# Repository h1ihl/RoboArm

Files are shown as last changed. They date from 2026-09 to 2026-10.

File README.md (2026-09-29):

# Desk Arm — Low-Cost 3-DOF Desktop Robot Arm

A small tabletop 3-DOF robot arm (base yaw, shoulder, elbow, plus a two-finger
gripper), 3D-printed and built on hobby servos, aimed at CAD $50–70 and hard
capped at $100. V1 is a manually/programmatically controlled physical arm.
V2 (not started) adds a camera, object detection and an AI agent on top of the
same control API.

**Status: Phase 0 (Requirements) complete — design review signed off, CAD not
yet started.** See [`docs/requirements.md`](docs/requirements.md) for the
decision gate and [`docs/planning_guide.pdf`](docs/planning_guide.pdf) for the
full write-up.

## Chosen configuration — Configuration B

| | |
|---|---|
| Reach | 315 mm |
| Payload | 55 g |
| Base / Shoulder / Elbow | MG90S / MG996R / MG996R |
| Wrist (slaved, keeps jaws level) | SG90 |
| Gripper | MG90S, two-finger compliant jaws |
| Controller | ESP32 DevKit, USB serial |
| Power | 6 V 3 A regulated, separate from MCU 5 V rail |
| Shoulder safety factor | 2.44 |
| Purchase cost | ≈ CAD $59 (typical lab sourcing) |

Fallback Configurations A (ultra-budget, $48–55), C (university-sourced,
$17–35) and D (stronger, $85–95) share the same CAD, firmware and software —
see §14 of the planning guide.

## Repository layout

```
README.md                    you are here
docs/                         requirements, calculations, BOM, procedures, wiring diagram, the LaTeX planning guide + PDF
firmware/arm_firmware/        ESP32 sketch — servo control, joint limits, slew limiting, serial protocol
software/                     Python control layer — kinematics, trajectory, transport, CLI
cad/                           SolidWorks project layout, parametric strategy, part/config naming (files added as they're modelled)
calculations/                  the torque/mass/stability numbers as a runnable, checkable script
artifacts/                     saved copies of design artifacts (e.g. the interactive design-review page)
tools/latex/                   self-contained LaTeX engine used to build docs/planning_guide.pdf
```

## Documentation map

| Doc | Covers |
|---|---|
| [`docs/requirements.md`](docs/requirements.md) | DOFs, dimensions, payload, workspace, budget, the decision gate |
| [`docs/actuator_selection.md`](docs/actuator_selection.md) | Torque calculations, servo table, SG90 vs MG90S gripper decision |
| [`docs/mechanical_design.md`](docs/mechanical_design.md) | Geometry, mass budget, material assignment, print orientation rules, SolidWorks parametric strategy |
| [`docs/electronics.md`](docs/electronics.md) | Controller choice, wiring, serial protocol |
| [`docs/wiring_diagram.svg`](docs/wiring_diagram.svg) | Full wiring diagram — pin-out, power rail, grounding |
| [`docs/power_system.md`](docs/power_system.md) | Current budget, supply spec, brownout protection |
| [`docs/kinematics.md`](docs/kinematics.md) | Forward/inverse kinematics derivation, validation order |
| [`docs/bill_of_materials.md`](docs/bill_of_materials.md) | BOM A (purchase) and BOM B (university-sourced) |
| [`docs/assembly.md`](docs/assembly.md) | Build order, torque/adhesive notes, calibration procedure |
| [`docs/testing.md`](docs/testing.md) | Per-phase test plan, acceptance criteria |
| [`docs/v2_ai_roadmap.md`](docs/v2_ai_roadmap.md) | What V2 adds and why V1's API doesn't need to change |
| [`docs/planning_guide.pdf`](docs/planning_guide.pdf) | All of the above, consolidated into one LaTeX-typeset document |

## Software quick start

```bash
cd software
python -m robot.kinematics        # runs the FK/IK self-test, no hardware needed
python cli.py --port COM5         # interactive control, once the arm is wired up
```

`software/robot/arm.py` exposes the six calls everything else — including the
future V2 agent — is meant to use: `home()`, `move_joints()`, `move_to()`,
`grip()`, `pickup()`, `place()`.

## Firmware quick start

Install the `esp32` board package (Boards Manager) and the `ESP32Servo`
library (Library Manager) in the Arduino IDE, open
`firmware/arm_firmware/arm_firmware.ino`, select your ESP32 board (e.g.
"ESP32 Dev Module"), upload, then talk to it at 115200 baud — `PING` should
answer `OK ARM v1`. Full command reference in `docs/electronics.md`.

## Build a fresh PDF

```powershell
.\tools\latex\tectonic.exe docs\planning_guide.tex --outdir docs
```

See `tools/latex/README.md` for details.

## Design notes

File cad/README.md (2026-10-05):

# CAD

No SolidWorks files exist yet — Phase 2 (Mechanical design) starts here.
SolidWorks files are proprietary binary formats this tool can't author, so
this folder currently documents the structure and naming convention to
build against, per `docs/mechanical_design.md`'s parametric strategy. Add
real `.SLDPRT` / `.SLDASM` files as they're modelled; keep this README's
part list in sync as the source of truth for what should exist.

## Layout

```
cad/
├── equations.txt     global variables, exported from SolidWorks — import into every new part
├── parts/            individual part files (.SLDPRT)
├── assemblies/        sub- and top-level assemblies (.SLDASM)
└── exports/           STEP/STL exports for printing and sharing
```

## Global parameters (one equations/variables file, referenced everywhere)

`equations.txt` is the exported copy of this table. Import it
(Tools > Equations > Import) into each new part; when a value changes,
change it once, re-export, and re-import into existing parts.

| Parameter | Symbol | Default (Config B) |
|---|---|---:|
| Shoulder height | `h0` | 75 mm |
| Upper arm length | `L1` | 120 mm |
| Forearm length | `L2` | 120 mm |
| Wrist→TCP length | `L3` | 75 mm |
| Link plate thickness | `t_link` | 3 mm |
| Link plate depth (bending direction) | `w_link` | 20 mm — matches the deflection calc in `calculations/engineering_calcs.py` |
| Twin-plate gap | `w_gap` | 20 mm — provisional, set by the elbow servo mount design |
| Bracket thickness | `t_bracket` | 4 mm |
| Pin diameter | `d_pin` | 4 mm (M4) |
| Gripper pivot pin diameter | `d_pin_gripper` | 3 mm (M3) |
| Nominal clearance | `c_fit` | 0.2 mm — **measured**, PLA (see below) |
| Gripper pivot clearance | `c_fit_pivot` | `c_fit` + 0.05 mm = 0.25 mm — chosen, not coupon-verified for free spin |

`c_fit` was confirmed with the tolerance coupon on 2026-10-01: Prusa
Core One, Prusament PLA, 0.4 mm nozzle, 0.2 mm layers — +0.20 mm gave the
best snug fit on both the M4 and M3 hole rows. PETG is still untested;
re-run the coupon in PETG before printing PETG parts (brackets, jaws, horn
adapters) and add a separate `c_fit_petg` if it lands somewhere else.
`c_fit_pivot` is the free-rotation clearance for the gripper jaw pins,
set to 0.25 mm (`c_fit` + 0.05 mm) — a chosen value between the snug 0.2 mm
fit and the original 0.3 mm estimate. Check a pin for free spin in the
printed 3.25 mm coupon hole before relying on it.

## Servo-pocket library feature (two-row design table)

| Row | Body (mm) | Mounting-ear span | Servos |
|---|---|---:|---|
| `standard` | 40.7 × 19.7 × 42.9 | 49.5 mm | MG996R, MG995, DS3218 |
| `micro` | 22.8 × 12.2 × 22.5 | 32 mm | MG90S, SG90, MG92B |

Every servo mount part references this feature and picks a row — swapping
an MG996R for an MG90S (or vice versa, per the fallback configurations in
`docs/requirements.md`) is then a design-table row change, not a redesign.

## Part list (target — Configuration B)

| Part | Qty | File (suggested) | Notes |
|---|---:|---|---|
| Base plate | 1 | `parts/base_plate.SLDPRT` | Includes ballast cavity + snap-lid feature, camera-mast mounting bosses for V2 |
| Ballast cavity lid | 1 | `parts/ballast_lid.SLDPRT` | Snap-fit |
| Ballast block | 1 | `parts/ballast_block.SLDPRT` | Milled mild steel, not printed — size the cavity pocket to this part once it's cut (`docs/mechanical_design.md` §Ballast); bolt or press-fit, don't leave it loose |
| Column | 1 | `parts/column.SLDPRT` | Carries the two 608ZZ bearings |
| Turret | 1 | `parts/turret.SLDPRT` | Bolts to base-servo horn |
| Shoulder bracket | 1 | `parts/shoulder_bracket.SLDPRT` | Print flat — see mechanical_design.md rule 1. FEA candidate. |
| Elbow bracket | 1 | `parts/elbow_bracket.SLDPRT` | Print flat, same rule. |
| Upper-arm side plate | 2 | `parts/upper_arm_plate.SLDPRT` | Twin-plate box section; symmetric, so one part printed twice. Spec below. |
| Forearm side plate | 2 | `parts/forearm_plate.SLDPRT` | Save As from the upper-arm plate, `L1` → `L2`; keep as a separate file so Config-A-Short (`L2 = 80 mm`) works |
| Link spacers | qty per BOM | `parts/link_spacer.SLDPRT` | Parametric tube, length = `w_gap`; bolt size is a free choice (M3 keeps it clear of the M4 pivots) |
| Servo-horn adapter | 3 | `parts/horn_adapter.SLDPRT` | Bolts to the servo's metal horn — never a printed spline |
| Wrist mounting face | 1 | `parts/wrist_face.SLDPRT` | Common 24×24 mm interface — fixed bracket / SG90 slave / future linkage all mount here |
| Fixed wrist bracket | 1 (alt.) | `parts/wrist_fixed.SLDPRT` | Configuration-A fallback |
| Gripper jaw | 2 | `parts/gripper_jaw.SLDPRT` | Mirror pair, meshed gear sectors, compliant tip |
| Gripper drive link | 1 | `parts/gripper_link.SLDPRT` | |
| Cable clip | qty as needed | `parts/cable_clip.SLDPRT` | Unloaded, PLA, print in whatever's on the machine |

### Link side plate spec (upper arm; forearm identical with `L2`)

- Profile: `w_link` (20 mm) deep slot, both ends rounded at radius
  `w_link / 2`, concentric with the pivot holes. Overall ≈ 140 × 20 mm
  at `L1 = 120 mm`.
- Thickness `t_link` (3 mm), printed flat, hole axes normal to the bed.
- Two pivot holes, diameter `d_pin + c_fit` (4.2 mm), centre-to-centre
  `L1` — all driven from variables, nothing typed in.
- A few spacer-bolt holes along the plate; the gap between the twin
  plates is `w_gap`, which the servo mount design drives.
- Symmetric profile so one file prints twice with no mirrored copy.
- Check: print one plate, pass an M4 bolt through both pivot holes and
  caliper the centre distance — 120 ± 0.2 mm.

## Configurations to define in the top-level assembly

| Configuration | `L2` | Notes |
|---|---:|---|
| `Config-A-Short` | 80 mm | Fallback geometry — see `docs/requirements.md` trigger conditions |
| `Config-B-Standard` | 120 mm | Default — matches the numbers throughout `docs/` |

## Before printing anything

Done for PLA (see Global parameters above). For PETG parts, print the
tolerance coupon described in `docs/mechanical_design.md` in PETG and
confirm `c_fit = 0.2 mm` is actually right for that material before
committing it globally.

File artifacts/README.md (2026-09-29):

# Artifacts

`design_review.html` is a saved copy of the interactive design-review page
published earlier in this project
(https://claude.ai/code/artifact/120ad4c1-6e6d-4bc8-b303-615aa0728409) --
open it directly in a browser, no server needed. It was the first pass
through the numbers, before they were re-derived as runnable code.

**Two figures in it are superseded.** `calculations/engineering_calcs.py`
(run against real Python, not hand-arithmetic) caught two rounding slips
that made it into this page but not into `docs/`:

| Figure | This page says | Corrected (docs/, planning_guide.pdf) |
|---|---|---|
| Base tipping safety factor, ballasted | 2.26 | **2.22** |
| Wrist-servo required torque / SF | 0.51 kg·cm / SF 3.5 | **0.58 kg·cm / SF 3.08** |

Neither changes any design decision (both still clear their safety-factor
floors comfortably) -- treat `docs/` and `docs/planning_guide.pdf` as
authoritative; keep this page as the design-review record, not as the
current numbers.

**Controller updated in place.** The page originally recommended an Arduino
Nano; it's been edited to match the later ESP32 swap (`docs/electronics.md`)
-- cost, pin/library notes, the 3.3 V servo-jitter risk, and every table
that named the controller. This one change was applied directly rather than
left as a footnoted discrepancy like the two figures above, since it's a
component substitution the rest of the page's numbers don't depend on.

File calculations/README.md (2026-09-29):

# Calculations

`engineering_calcs.py` is a runnable, self-checking reproduction of every
number in `docs/actuator_selection.md`, `docs/mechanical_design.md` and
`docs/planning_guide.pdf` — mass budget, joint torque, servo safety factors,
gripper force, base tipping stability, and printed-link deflection.

```
python calculations/engineering_calcs.py
```

Runs a self-test against the published figures first (raises `AssertionError`
if something no longer matches), then prints a full report. Change a
geometry or mass constant at the top of the file and re-run to see how every
downstream number moves — this is the tool to reach for before committing to
a fallback configuration (`docs/requirements.md`).

**Verified 2026-09-18** against Python 3.12 — all figures match the
published docs within rounding tolerance. This run is also what caught two
rounding slips in the original hand-worked design review before they made
it into the docs: the ballasted tipping safety factor is **2.22**, not 2.26,
and the wrist-servo torque is **0.58 kg·cm** (SF 3.08), not 0.51 (SF 3.5) —
both now corrected everywhere in `docs/`.

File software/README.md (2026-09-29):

# Software

Python control layer -- kinematics, trajectory shaping, the serial
transport, and the public `Arm` API everything (CLI, demo sequences, and
eventually the V2 agent) is meant to call through. Architecture and the
V1/V2 boundary are in `docs/electronics.md` and `docs/v2_ai_roadmap.md`.

## Install

```bash
pip install -r requirements.txt
```

Only needed for real hardware (`pyserial`). Kinematics and the demo
sequences run against a simulated arm with no dependencies at all.

## Layout

```
robot/
├── config.py        geometry, joint limits, workspace bounds, servo calibration -- the one file to tune
├── kinematics.py     fk(), ik(), reachable(), path_safe() -- see docs/kinematics.md
├── trajectory.py      eased joint-space interpolation for Cartesian moves
├── transport.py        serial line protocol + a SimulatedTransport for hardware-free testing
└── arm.py              class Arm -- the public API (home, move_joints, move_to, grip, pickup, place)
cli.py                  interactive shell: python cli.py --port COM5
sequences.py             demo/test routines used in docs/testing.md
```

## Try it with no hardware attached

```bash
python -m robot.kinematics     # FK/IK self-test
python sequences.py wave       # runs against a simulated arm, prints every command
python cli.py                  # interactive shell, simulated
```

Once the arm is wired up (`docs/assembly.md`), add `--port COM5` (or
whatever the ESP32 enumerates as) to `cli.py` / `sequences.py`, or pass
`port="COM5"` to `Arm()` directly.

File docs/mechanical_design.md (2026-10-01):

# Mechanical design

## Geometry

Equal-length links: `L₁ = L₂ = 120 mm`. Deliberate, not arbitrary — equal
lengths (a) make the printed parts nearly identical, so it's one parametric
sketch with two configurations rather than two separate designs, (b)
maximise the folded-to-extended reach ratio, and (c) put the workspace's
inner boundary where the turret already is instead of leaving dead space.
`h₀ = 75 mm` (shoulder height) is the minimum that lets the elbow fold
without hitting the turret; `L₃ = 75 mm` (wrist→TCP) covers jaw depth plus
clearance to grip a 30 mm object. Every dimension traces back to the torque
budget in `docs/actuator_selection.md` — none were picked for looks.

| Parameter | Value |
|---|---|
| Shoulder height h₀ | 75 mm |
| Upper arm L₁ | 120 mm |
| Forearm L₂ | 120 mm |
| Wrist→TCP L₃ | 75 mm |
| Max TCP reach | 315 mm |
| Base footprint | 180 × 180 mm |
| Jaw opening | 0–55 mm |

## Structure: twin side plates

Links are two printed side plates on printed spacers — a box section that's
stiff in bending, prints flat with no supports, and puts every bolt in
double shear. Roughly 14 unique parts / 20 printed pieces / ~300 g of
filament / 18–22 h print time total for the arm.

## Material assignment

| Part | Material | Why |
|---|---|---|
| Base plate, column, turret | PLA | Stiffness and flatness; nothing here is impact-loaded |
| Upper arm, forearm links | PLA | E ≈ 3.5 GPa vs. PETG's 2.0 — 75% stiffer per section; deflection is what matters in a link |
| Shoulder and elbow brackets | PETG | Highest bending stress in the machine, and bending is where poor layer adhesion shows up first |
| Servo horn adapters | PETG | Small, bolted, loaded in a direction that wants to peel layers apart |
| Gripper jaws | PETG | Designed to flex (see compliant tip, actuator_selection.md); PLA would snap at the flex section |
| Spacers, clips, tray | PLA | Unloaded — print in whatever's on the machine |
| Ballast block | Mild steel, milled | Not printed — see Ballast below |

## Ballast

A solid milled block, not loose fill (sand, washers, etc.) — a fixed,
known mass at a fixed position matches the stability calc's assumption
exactly, and doesn't shift the CoM as the base rotates the way loose fill
can.

**Mild steel, ~50–55 cm³ for the 400 g target** (density ≈ 7.85 g/cm³):
a 60 × 60 × 15 mm block is ≈424 g, comfortably clearing the minimum with
margin to spare for the mass the stability calc doesn't otherwise account
for (hardware, wiring, ballast-cavity lid). Steel over aluminium here
specifically for the footprint: at the same mass, aluminium
(≈2.70 g/cm³) needs ~3× the volume, and the ballast cavity is already
competing for space with the column and base-servo mount inside the
180 × 180 mm base. Weigh the actual cut block before final install and
trim (or pick a slightly larger blank) to clear 400 g — mild steel density
varies enough between alloys (7.75–7.87 g/cm³) that this is a
measure-don't-assume step, consistent with the rest of this project's
philosophy on anything safety-factor-adjacent.

**Bolt or press-fit it into the cavity** — don't let it sit loose. A block
free to slide during the base's rotation defeats the fixed-CoM assumption
above, and turns a designed-in stability margin into an unmeasured one.

Design the ballast cavity pocket to the block's actual milled dimensions
once cut, not the other way around — CAD (Phase 2) hasn't started yet, so
there's no existing pocket geometry to retrofit.

Print settings throughout: 0.4 mm nozzle, 0.2 mm layers, **4 perimeters**,
30% gyroid infill, 5 top/bottom layers. Perimeter count dominates strength in
a thin printed part — 4 walls at 20% infill beats 2 walls at 60%, and weighs
less.

## Layer orientation — the three rules that decide whether this works

1. **Print brackets flat, never standing up.** A shoulder bracket printed
   upright has its layer planes perpendicular to the bending stress, so the
   load tries to peel layers apart — roughly 40–60% of in-plane strength.
   Printed flat, the same stress runs along continuous extrusions instead.
2. **Every bolt hole axis is normal to the build plate.** Bolts then clamp
   *across* layers in compression, which printed plastic handles well,
   instead of trying to split them apart.
3. **Never print a servo spline.** A printed 25-tooth spline will round off —
   not might, will. Bolt the metal horn that came with the servo to the
   printed part with 2–3 M2 screws and let the horn take the torque. This is
   the single most common failure mode in printed arms, and it's designed
   out from part one rather than discovered after a reprint.

## Where SolidWorks Simulation earns its time — and where it doesn't

**Worth running (2 studies):**
- **Shoulder bracket** — 0.44 N·m through a bolted interface with a stress
  concentration at the servo cutout. The one part where intuition is
  unreliable.
- **Upper-arm link** — check the elbow-servo pocket; expect the answer to be
  "add a 3 mm fillet."

**Not worth running:** everything else. The hand calculation below already
answers the question, and running FEA on a part that's obviously fine just
burns an afternoon.

```
Upper-arm tip deflection, 1.3 N at 120 mm, twin 20 × 3 mm plates:
  I = 2 × (3 × 20³)/12 = 4000 mm⁴
  δ = FL³/(3EI) = 1.3 × 120³ / (3 × 2500 × 4000) = 0.075 mm
```

**Seventy-five microns.** The structure is ~80× stiffer than the servo
backlash it's bolted to (see `docs/kinematics.md` — repeatability is
backlash-limited to ±5–8 mm). **Do not thicken these links.** Every gram
added buys nothing measurable and costs shoulder safety factor directly —
this is the one place in the project where "more robust" would make the
robot objectively worse.

If FEA is run on either study, use orthotropic material properties (printed
plastic is not isotropic) and treat the result as a comparison between two
design variants, not an absolute number.

## Parametric strategy for SolidWorks

- **One global variable/equations file** driving `L1`, `L2`, `L3`, `h0`,
  plate thickness and pin diameter across every part.
- **A servo-pocket library feature with a two-row design table** — standard
  (MG996R: 40.7 × 19.7 × 42.9 mm body, 49.5 mm mounting-ear span) and micro
  (MG90S/SG90: 22.8 × 12.2 × 22.5 mm, 32 mm span). Every servo mount
  references it, so swapping an MG996R for an MG90S is a configuration
  change, not a redesign. This is what makes Configurations A–D one robot
  instead of four (brief §28).
- **Assembly mated to reference planes and axes**, never face-to-face
  between links, so changing `L1` rebuilds the assembly instead of
  erroring it out.
- **Configurations**: `Config-A-Short` (`L2 = 80 mm`) and
  `Config-B-Standard` (`L2 = 120 mm`) from the same part files.
- **0.2 mm nominal clearance** on every pin and pocket. Print a tolerance
  coupon first (a small test part with a few pin/hole pairs at different
  clearances) and adjust once, globally, via the variables file — cheaper
  than reprinting full parts to find the right fit.
  **Measured 2026-10-01** (Prusa Core One, Prusament PLA, 0.4 mm nozzle,
  0.2 mm layers, 3 mm plate, holes axis-normal to the bed): +0.20 mm gave
  the best snug fit on both the M4 (`d_pin`) and M3 (`d_pin_gripper`) hole
  rows, so `c_fit = 0.2 mm` stands as a measured value, not an assumption.
  The calculated estimate beforehand was ~0.15 mm for PLA structural fits —
  close, but the measurement wins. Still open: PETG (untested, needs its own
  coupon) and the free-rotation `c_fit_pivot`, set to 0.25 mm
  (`c_fit` + 0.05 mm) by choice for the gripper jaw pins — it still wants a
  spin-freely check in the printed 3.25 mm coupon hole rather than the
  snug-fit one used for `c_fit`.

## Suggested file layout (see `cad/README.md`)

```
cad/
├── parts/            individual SolidWorks part files (.SLDPRT)
├── assemblies/        sub- and top-level assemblies (.SLDASM)
└── exports/           STEP/STL exports for printing and sharing
```

No SolidWorks files exist yet — Phase 2 (Mechanical design) starts here.
`cad/README.md` has the part list, naming convention and design-table spec
to build against.

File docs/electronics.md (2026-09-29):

# Electronics

## Architecture

```
   PC ──USB──▶ ESP32 ──────5 × PWM signal──▶ servos
                    │                              ▲
                    └──── GND ═══════ common ══════╪═══ GND
                                                   │
    6 V 3 A supply ──fuse──┬── 2 × 1000 µF ────────┘
                           └── V+ rail to all five servos
```

Full pin-out and wiring shown in [`docs/wiring_diagram.svg`](wiring_diagram.svg)
— open it in a browser, no build step needed.

## Controller: ESP32 (DevKitC or equivalent)

**Revised from the original Arduino Nano choice** — see the reasoning below;
nothing else about the architecture changed. The ESP32 is 3.3 V logic where
the Nano was native 5 V, which is the one real trade-off:

- Hobby servos decode PWM through an analog RC input stage, and in
  practice a 3.3 V "high" clears that threshold on the SG90/MG90S/MG996R
  family used here — this is a well-worn combination, not a gamble. The
  documented failure mode is occasional jitter on a specific unit, not a
  hard incompatibility. **Test each servo before final assembly**; if one
  jitters, add a 74HCT125/74AHCT125 quad buffer (~$1, one chip covers all
  five signal lines) between the GPIO and that signal wire to get a clean
  5 V pulse. Not included in the base BOM because most builds won't need
  it — this is the documented fallback, not a default component.
- Requires the **ESP32Servo** library instead of the stock `Servo.h` (the
  ESP32 Arduino core doesn't ship one); API is functionally the same
  `attach()` / `writeMicroseconds()` pair, just backed by the chip's LEDC
  PWM peripheral instead of a hardware timer. See
  `firmware/arm_firmware/arm_firmware.ino` for the setup boilerplate this
  adds (timer allocation, per-channel pulse range).
- In exchange: a dual-core chip with far more flash/RAM/GPIO than this
  project needs, a similar street price to the Nano, and — unused in V1,
  but noted for `docs/v2_ai_roadmap.md` — Wi-Fi/BT already on the board if
  V2 ever wants the arm untethered from the PC.

| Board | Cost | Logic | Assessment |
|---|---:|---|---|
| **ESP32 DevKit (chosen)** | $12 | 3.3 V | `ESP32Servo` library, USB-serial via onboard CP2102/CH340 — install its driver before you need it. Test 3.3 V servo latching per-unit; level-shifter fallback above. |
| Arduino Nano | $9 | 5 V | Native servo levels, no latching question, stock `Servo.h`. The straightforward fallback if an ESP32 isn't available or a servo won't latch cleanly at 3.3 V even with a level shifter — same firmware minus the ESP32Servo-specific setup calls, same pin roles, same protocol. |
| Arduino Uno | — | 5 V | Electrically identical to the Nano, bulkier. Take this if the lab has one. |
| Raspberry Pi Pico | $7 | 3.3 V | Better PWM hardware, cheaper, MicroPython instead of Arduino C++. Same 3.3 V latching consideration as the ESP32. |

**Deliberately not included:**
- **PCA9685 driver board** — five servos fit on five ESP32 GPIOs with the
  `ESP32Servo` library. The board solves a problem (running out of timers)
  that starts around twelve servos. $6 and a whole I²C bus for nothing here.
- **Encoders / current sensing** — hobby servos have no position-feedback
  path to the MCU; external encoders would mean closing a loop the servo
  already closes internally. Real value, wrong project.
- **Limit switches** — servos are absolute-position devices; they know where
  they are at power-on. Homing switches solve a stepper problem this arm
  doesn't have.

Assembly is a small piece of perfboard on the base plate: five 3-pin servo
headers, a barrel jack, the bulk capacitors, a fuse, and jumper wires to the
ESP32's GPIO/GND header pins — under an hour of soldering.

### GPIO pin selection

`firmware/arm_firmware/arm_firmware.ino` uses GPIO13 (base), GPIO14
(shoulder), GPIO27 (elbow), GPIO26 (wrist), GPIO25 (gripper) — five
general-purpose, LEDC-PWM-capable pins, chosen to avoid:

- **GPIO 0, 2, 5, 12, 15** — boot-strapping pins. A servo signal wire
  yanking one of these during power-on can change the chip's boot mode.
- **GPIO 34–39** — input-only, can't drive a servo signal at all.
- **GPIO 1, 3** — UART0, i.e. the USB-serial link back to the PC.

Any other general-purpose GPIO works as a substitute if a specific board's
layout makes a different pin more convenient — there's nothing special
about this exact set beyond satisfying the three exclusions above.

## Serial protocol

ASCII, line-oriented, one command per line, every command answered.
Debuggable from a plain serial monitor with no tooling — which matters a
great deal on the first evening the arm doesn't move.

| Command | Reply | Purpose |
|---|---|---|
| `PING` | `OK ARM v1` | Port identification and liveness |
| `J <base> <sh> <el>` | `OK` \| `ERR LIMIT <joint>` | Absolute joint angles, degrees. Wrist follows automatically. |
| `G <0-100>` | `OK` | Gripper, 0 = closed, 100 = open |
| `US <ch> <µs>` | `OK` \| `ERR RANGE` | Raw pulse width — calibration only, still bounded by limits.h. `ch` is `B`/`S`/`E`/`W`/`G` (base/shoulder/elbow/wrist/gripper) |
| `HOME` | `OK` | Slew to the safe folded pose |
| `STOP` | `OK` | Freeze at the current position |
| `REL` | `OK` | Detach all servos — kills holding buzz, lets you move the arm by hand |
| `STAT` | `<angles> <µs>` | Current commanded state |

## Firmware structure

```
firmware/arm_firmware/
├── arm_firmware.ino   serial parser, 50 Hz update loop
├── limits.h           per-joint µs bounds — hard clamp, no override from the PC
└── slew.h             60°/s rate limiter, so nothing ever slams
```

The split is deliberate: **the firmware owns safety, the PC owns
intelligence.** Joint limits and slew limiting live on the ESP32 and can't be
bypassed by a buggy Python script — or, later, by a confused AI agent.
Everything else (kinematics, sequencing, the CLI) lives on the PC where it's
easy to change without re-flashing.

## Wiring notes

- Servo ground and ESP32 ground **must** be joined, or the PWM signal has no
  reference and servos twitch randomly.
- Never power the servo rail from the ESP32's 5V/VIN pin or its USB
  connection — see `docs/power_system.md` for why.
- Keep servo signal wires away from the barrel-jack input leads to avoid
  switching noise on the PWM lines.
- Full pin-out, colour-coded nets and this checklist as a picture:
  [`docs/wiring_diagram.svg`](wiring_diagram.svg).

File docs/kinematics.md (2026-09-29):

# Kinematics

No DH tables, no Jacobians, no numerical solver. Base rotation decouples
completely from shoulder/elbow, leaving a two-link planar problem with a
closed-form solution — implemented in full in
`software/robot/kinematics.py` (~40 lines including workspace checks, with a
self-test that reproduces every number below).

## Forward kinematics

```
r = L₁·cos θ₁ + L₂·cos(θ₁+θ₂) + L₃
z = h₀ + L₁·sin θ₁ + L₂·sin(θ₁+θ₂)
x = r·cos θ₀        y = r·sin θ₀
```

`L₃` adds directly to `r` with no trig term — that's the payoff of the
levelled wrist (`docs/requirements.md` — the SG90 slaved axis). Without it,
`L₃` would carry a `cos(θ₁+θ₂+θ₃)` factor and the inverse problem stops
being closed-form.

## Inverse kinematics

```
θ₀ = atan2(y, x)

r' = √(x²+y²) − L₃          # wrist-pivot radius
z' = z − h₀

D  = (r'² + z'² − L₁² − L₂²) / (2·L₁·L₂)
     # |D| > 1  →  target unreachable. Check before acos().

θ₂ = −acos(D)                                    # negative root = elbow-up
θ₁ = atan2(z', r') − atan2(L₂·sin θ₂, L₁ + L₂·cos θ₂)
θ₃ = −(θ₁ + θ₂)                                  # slaved wrist, jaws level
```

The two `acos` roots are elbow-up and elbow-down. Elbow-down puts the elbow
below the table on nearly every desk-height target, so the solver takes the
negative root unconditionally and never has to choose between them.

## Validation, in this order, before anything moves

1. **Reachability** — `|D| ≤ 1` and `130 ≤ √(x²+y²) ≤ 290` (mm).
2. **Joint limits** — every θ inside its mechanical range
   (`docs/requirements.md` §DOF / `firmware/arm_firmware/limits.h`).
3. **Table clearance** — `z ≥ 10 mm`, and the elbow itself above the table,
   which the elbow-up choice doesn't guarantee near the inner boundary.
4. **Path check** — for a Cartesian move, interpolate ~20 waypoints and
   validate each. A straight line between two legal poses can still pass
   through an illegal one.

`software/robot/kinematics.py` implements all four as `reachable()` and
`path_safe()`, called from `arm.py::move_to()` before any command reaches
the serial port.

## Accuracy limit: backlash, not mathematics

An MG996R has 1–2° of gear lash plus potentiometer deadband. At the 240 mm
shoulder+elbow lever, 1.5° is **6 mm at the gripper**. Expect **±5–8 mm**
repeatability and design around it, not against it:

- Approach every target from the same direction, so lash is always taken up
  the same way.
- Let the 55 mm jaw opening (and the gripper's compliant tip,
  `docs/actuator_selection.md`) absorb the rest.

No amount of IK precision buys back a millimetre of this — it's a mechanical
limit, not a software one.

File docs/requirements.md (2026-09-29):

# Requirements — Phase 1

## Scope

V1: a mechanically and electronically functional 3-DOF arm, controlled
manually or programmatically from a PC over USB. No camera, no vision, no AI
agent — that's V2, and V1's software is only required not to block it.

## Degrees of freedom

1. **Base yaw** — rotates the whole arm about a vertical axis.
2. **Shoulder** — raises/lowers the upper arm in the vertical plane the base
   is currently pointed at.
3. **Elbow** — folds the forearm relative to the upper arm, same plane.
4. **Gripper** (not counted as a DOF for positioning) — opens/closes a
   two-finger claw.
5. **Wrist pitch** — present in hardware (an SG90) but *not* an independently
   commanded axis. Firmware slaves it to `−(θ₁+θ₂)` so the gripper stays level
   in every pose. See `docs/kinematics.md`.

This is a positioner with 3 controllable spatial DOF (x, y, z) plus grip —
exactly matching brief §5/§6, no more.

## Target dimensions

| Parameter | Target (brief) | Chosen |
|---|---|---|
| Base footprint | 150–200 mm | 180 × 180 mm |
| Reach | 250–350 mm | 315 mm (315 mm kinematic max, 290 mm practical/software limit) |
| Overall height | 250–400 mm | ~340 mm (arm vertical, incl. gripper) |

Link lengths: shoulder height `h₀ = 75 mm`, upper arm `L₁ = 120 mm`, forearm
`L₂ = 120 mm`, wrist→TCP `L₃ = 75 mm`. Equal `L₁ = L₂` was a deliberate
choice — see `docs/mechanical_design.md` §Geometry.

## Payload

**Design payload: 55 g** at full 315 mm reach — covers pens, small tools,
USB sticks, small project boxes, small electronics. Not sized for anything
heavier; see `docs/actuator_selection.md` for the torque math that sets this
number, and `docs/requirements.md` §Fallback below for what changes if it
needs to move.

## Workspace

Reachable TCP envelope (vertical half-plane, swept ±90° about the base axis):

| Bound | Value | Set by |
|---|---|---|
| Outer radius | 315 mm kinematic / 290 mm practical | Link length / IK conditioning near full extension |
| Inner radius | 130 mm | Forearm-to-turret collision |
| Floor | z = 10 mm | Jaw-to-table clearance, enforced in firmware |
| Ceiling | z = 315 mm | Arm vertical |
| Base sweep | ±90° | No slip ring in V1 — full 360° would need one |

Usable desk area: an annular sector, 130–290 mm radius, 180° — about
0.09 m² directly in front of the base.

## Budget

- Target personal spend: **CAD $50–70**
- Absolute maximum: **CAD $100**
- Actual (Configuration B, typical lab sourcing): **≈ $59**
- Actual if buying literally everything: **≈ $90** — still under the ceiling

Full breakdown in `docs/bill_of_materials.md`.

## Servo requirements (summary — full derivation in actuator_selection.md)

| Joint | Servo | Required torque | Rated (6 V) | Safety factor |
|---|---|---:|---:|---:|
| Base | MG90S | 0.30 kg·cm | 2.20 kg·cm | 7.3 |
| Shoulder | MG996R | 4.51 kg·cm | 11.00 kg·cm | 2.44 |
| Elbow | MG996R | 2.00 kg·cm | 11.00 kg·cm | 5.50 |
| Wrist (slaved) | SG90 | 0.58 kg·cm | 1.80 kg·cm | 3.08 |
| Gripper | MG90S | 0.82 kg·cm | 2.20 kg·cm | 2.7 |

Floor for every joint: SF ≥ 2.0 — roughly the point below which a hobby
servo holding a static pose runs hot rather than idling near stall current.

## Decision gate (answered)

The design review (see `docs/planning_guide.pdf` §14 and its footer) posed
four questions before implementation started. Recorded answers:

1. **Configuration B**, built up from A rather than starting at D.
2. **SG90 slaved wrist: in.** $3 and 17 g for level jaws in every pose.
3. **University sourcing:** assume lab-available — controller, power supply
   (bench PSU for bring-up), fasteners, wire, bearings, filament. Budget the
   MG996R pair and MG90S/SG90 as purchased.
4. **315 mm / 55 g is the right target** — no known heavier payload
   requirement.

## Fallback trigger conditions

Per brief §22–25, don't jump configurations speculatively. Re-open this
document and move to the next configuration only if one of these actually
happens during build/test:

- **A → B**: if $50–55 genuinely isn't obtainable (all-purchase, no lab
  access) — shrink to 275 mm reach / 30 g payload instead of upgrading
  actuators.
- **B → D**: only if a joint measures below SF 1.5 *after* assembly (not
  predicted — measured), or repeated stalls/overheating occur at rated
  payload after the compliant-jaw and slew-limit mitigations are in place.
- **Any → C**: whenever a lab visit confirms specific components are on the
  shelf; swap in, keep everything else.

See `docs/planning_guide.pdf` §15 (component fallbacks) and §14 (comparison
table + decision trail) for the full reasoning.

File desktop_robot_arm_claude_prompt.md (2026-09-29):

# Project: Low-Cost 3-DOF Desktop AI Robot Arm

I want to design and build a **small tabletop 3-DOF robotic arm** as a personal engineering/hobby project.

The eventual goal is to turn it into a **tabletop AI assistant** that can interact with objects on my desk. For example, an AI agent could eventually tell the arm to pick up an item I need, move something out of the way, bring an object closer, etc.

However, the project must be developed in two versions:

- **V1 — Basic robotic arm:** mechanically and electronically functional arm that I can control manually/programmatically.
- **V2 — AI assistant:** add a camera, computer vision, AI agent, object detection, and higher-level control.

**Do NOT start with the AI system. V1 is purely about building a functional physical robot.**

---

# 1. PROJECT CONSTRAINTS

This is intentionally a **small, inexpensive tabletop hobby robot**.

Target personal spending:

**CAD $50–70**

Absolute maximum:

**CAD $100**

Do not turn this into a $200–500 robotics project.

The goal is to learn from the mechanical, electrical, and software design while actually being able to build the robot.

Prioritize:

1. Low cost
2. Simplicity
3. Reliability
4. Ease of fabrication
5. Adequate performance
6. Expandability toward V2

---

# 2. UNIVERSITY RESOURCES AVAILABLE

I am an engineering student and have access to a university engineering environment with **a variety of motors, electronics, components, tools, and equipment**.

I may be able to obtain or borrow things such as:

- Hobby servos
- DC motors
- Stepper motors
- Brushless motors
- Microcontrollers
- Sensors
- Wiring
- Breadboards
- Connectors
- Fasteners
- Bearings
- Power supplies
- Motor drivers
- Miscellaneous electronics

Therefore:

**DO NOT automatically include every component in the purchase budget.**

If a component is something that I could reasonably source from the university, identify it as:

> **Potentially university-sourced**

rather than assuming I need to buy it.

However, do not assume that I have a specific component unless the design can reasonably work with common university lab equipment.

For components where a specific model is important, give me a recommended inexpensive option to purchase as a fallback.

The CAD $50–70 budget should primarily represent the **things I realistically need to purchase myself**.

---

# 3. FABRICATION / CAD

I will be **3D printing essentially all of the mechanical components**.

Available printing materials:

- PLA
- PETG

I will design the mechanical components in:

**SolidWorks**

Design the robot specifically with this manufacturing method in mind.

The mechanical design should consist primarily of:

- 3D-printed parts
- Standard screws/bolts/nuts
- Cheap bearings or bushings where appropriate
- Hobby servos
- Simple shafts/pins
- Minimal purchased hardware

Do not design parts that require CNC machining, machining-grade tolerances, aluminum fabrication, carbon fiber, or other expensive manufacturing unless there is a compelling reason.

If a component can be redesigned as a simple 3D-printed part, prefer that solution.

---

# 4. 3D PRINTING DESIGN PHILOSOPHY

Design for easy printing and assembly.

Use sensible:

- Wall thicknesses
- Fillets
- Print orientations
- Infill
- Layer directions
- Bolt locations
- Servo mounting patterns

Pay attention to **3D-printing-specific strength**.

For example, consider whether a joint is likely to fail because of layer separation rather than simply assuming isotropic material strength.

For high-load components such as:

- Shoulder brackets
- Elbow brackets
- Base
- Servo mounts

consider the direction of loading relative to the print layers.

Recommend PLA vs PETG where appropriate.

Do not over-engineer the printed components.

---

# 5. ROBOT ARCHITECTURE

Design a **3-DOF tabletop robot arm**.

The baseline concept should be:

1. Base rotation
2. Shoulder
3. Elbow

Plus:

4. Servo-powered gripper

The arm should be capable of:

- Rotating around the base
- Reaching across a desk
- Moving the end effector vertically
- Opening/closing the gripper
- Picking up lightweight objects
- Moving objects short distances
- Placing objects back down

The intended payload is lightweight desk objects.

Examples:

- Pens
- Small tools
- Small boxes
- Lightweight containers
- Small electronics
- Other objects of similar size/weight

Do not optimize for heavy payloads.

---

# 6. ACTUATOR SELECTION

Research inexpensive servo options.

Potential candidates include:

- SG90
- MG90S
- MG996R
- MG995
- DS3218
- Other inexpensive hobby servos

But don't simply choose the largest servo.

Calculate the approximate torque requirements based on:

- Arm length
- Link mass
- Payload
- Joint geometry
- Worst-case position
- Safety factor

Then select the cheapest actuator that provides sufficient performance.

Pay particular attention to the shoulder joint because it will likely experience the highest torque.

Compare the options in a table.

For example:

| Joint | Servo | Required Torque | Rated Torque | Safety Factor |
|---|---|---:|---:|---:|
| Base | ??? | ??? | ??? | ??? |
| Shoulder | ??? | ??? | ??? | ??? |
| Elbow | ??? | ??? | ??? | ??? |
| Gripper | ??? | ??? | ??? | ??? |

For the gripper specifically, compare:

**SG90 vs MG90S**

and explain which makes more sense.

If university-sourced servos make more sense than purchasing cheap servos, account for that as an alternative.

---

# 7. ARM DIMENSIONS

Keep the arm genuinely small.

Target approximately:

- Base: 150–200 mm footprint
- Reach: 250–350 mm
- Overall height: 250–400 mm

These are starting targets rather than strict requirements.

Use the torque calculations to determine the final dimensions.

If reducing arm length substantially allows us to use cheaper servos, consider doing that.

Do not make the arm larger just because it looks more impressive.

---

# 8. GRIPPER

V1 must include a basic claw.

Use either:

- SG90
- MG90S

depending on the engineering analysis and price.

The gripper should be:

- 3D printable
- Simple
- Lightweight
- Easy to replace
- Capable of gripping small desk objects

Do not design an elaborate multi-finger gripper.

A simple two-finger claw is preferred.

Consider whether the gripper should use:

- Direct servo actuation
- Simple linkage
- Gear mechanism

Choose the simplest reliable option.

---

# 9. ELECTRONICS

V1 should have simple electronics.

Potential microcontrollers:

- Arduino Nano
- ESP32
- Raspberry Pi Pico
- Similar inexpensive board

Choose based on cost and simplicity.

The controller needs to:

- Control all servos
- Enforce joint limits
- Receive movement commands
- Execute predefined positions
- Execute movement sequences

A PC connection would be useful because the PC can eventually become the interface for V2.

Do not add unnecessary sensors or electronics.

---

# 10. POWER

Design a proper servo power system.

Do not power multiple servos directly from a microcontroller's 5V pin if the current requirements make that unsafe.

Calculate approximately:

- Servo current
- Peak current
- Supply voltage
- Required power

Then recommend a cheap power source.

If I can source an appropriate supply from the university, identify that as a possible way to reduce cost.

---

# 11. V1 CONTROL

V1 should allow manual/programmatic control.

A good architecture would be:

**PC → USB → Microcontroller → Servos**

Create simple commands such as:

```text
BASE 90
SHOULDER 60
ELBOW 120
GRIP OPEN
GRIP CLOSE
```

and/or higher-level commands such as:

```text
MOVE X Y Z
PICKUP
RELEASE
HOME
```

Implement a simple Python program if practical.

Do not introduce ROS or a complicated robotics framework.

---

# 12. KINEMATICS

Implement basic robot-arm kinematics.

For a 3-DOF arm, support:

### Forward kinematics

Joint angles → end-effector position

and ideally:

### Inverse kinematics

Desired X/Y/Z → joint angles

Use the simplest mathematical model appropriate for the arm.

Document the equations clearly.

Account for:

- Servo limits
- Mechanical limits
- Reachable workspace
- Collision possibilities
- Ground/table clearance

Do not turn this into an advanced robotics research project.

---

# 13. MECHANICAL ENGINEERING

Since this is an engineering project, include reasonable engineering calculations.

At minimum calculate:

### Joint torque

For example:

\[
\tau = Fd
\]

and account for the mass of downstream links and payload.

### Safety factor

Compare calculated torque against servo torque.

### Base stability

Estimate whether the arm could tip over in a worst-case configuration.

### Structural strength

Identify high-stress printed components.

If useful, I can perform FEA in SolidWorks, so identify components where SolidWorks Simulation would actually be useful.

Do not require FEA for every single part.

Use engineering analysis where it provides useful information.

---

# 14. SOLIDWORKS DESIGN

The CAD should be organized like a real engineering project.

Use sensible:

- Part files
- Assemblies
- Configurations where useful
- Mates
- Reference geometry
- Design tables only if actually necessary

The assembly should make it easy to modify:

- Arm length
- Servo locations
- Joint positions
- Gripper
- Base dimensions

Consider designing the servo mounts parametrically so different inexpensive servos can be accommodated without redesigning the entire arm.

---

# 15. V1 SOFTWARE ARCHITECTURE

Keep the software modular enough that V2 can build on it.

For example:

```text
PC
 │
 ▼
Python Control Layer
 │
 ├── Manual Control
 ├── Position Commands
 ├── Kinematics
 └── Future AI Agent
 │
 ▼
Microcontroller
 │
 ├── Servo Control
 ├── Joint Limits
 └── Safety Logic
 │
 ▼
Robot Arm
```

The future AI agent should eventually be able to call the same movement functions used by the V1 control system.

---

# 16. V2 — AI TABLETOP ASSISTANT

After V1 is proven functional, V2 can add:

### Hardware

- Camera
- Computer
- Optional additional sensors

### Software

- Computer vision
- Object detection
- Object localization
- AI agent
- Natural-language commands
- High-level task planning

Eventually I want to be able to say something like:

> "Pick up my screwdriver and put it beside my laptop."

The eventual system could:

1. Understand the command
2. Identify the screwdriver
3. Locate it on the desk
4. Convert camera coordinates into robot coordinates
5. Calculate arm movement
6. Move the gripper to the screwdriver
7. Close the gripper
8. Move the object
9. Release it

But:

**DO NOT IMPLEMENT THIS IN V1.**

Only create the architecture so that V2 can be added later without rebuilding the entire project.

---

# 17. BUDGET

Create two BOMs.

### BOM A — Things I need to purchase

Target:

**CAD $50–70**

Maximum:

**CAD $100**

### BOM B — Potentially university-sourced

List things that could reasonably be obtained from university labs/workshops.

Example:

| Component | Purchase Cost | University Alternative |
|---|---:|---|
| Microcontroller | $X | Arduino/ESP32/Pico |
| Servos | $X | Existing hobby servos |
| Bearings | $X | Lab stock |
| Power supply | $X | Lab supply |
| Wiring | $X | Lab stock |
| Hardware | $X | Workshop stock |

Do not artificially inflate the project cost by assuming I have to purchase everything.

---

# 18. PROJECT PHASES

Structure the project as:

## Phase 1 — Requirements

Determine:

- DOFs
- Dimensions
- Payload
- Workspace
- Servo requirements
- Budget

## Phase 2 — Mechanical design

Design the complete arm in SolidWorks.

## Phase 3 — Prototype

3D print the components in PLA/PETG.

## Phase 4 — Electronics

Connect:

- Microcontroller
- Servo power
- Servos

## Phase 5 — Firmware

Implement:

- Servo control
- Joint limits
- Home position
- Basic movement commands

## Phase 6 — Kinematics

Implement:

- Forward kinematics
- Inverse kinematics
- Cartesian movement

## Phase 7 — Testing

Test:

- Individual joints
- Full arm
- Gripper
- Payload
- Repeatability
- Stability
- Servo heating/current

## Phase 8 — V2

Only after V1 works:

- Camera
- Vision
- AI agent
- Object manipulation

---

# 19. DOCUMENTATION

Create useful documentation, but **do not over-document just for the sake of having documentation.**

I want documentation that helps me actually build and understand the project.

Include:

```text
README.md
docs/
├── requirements.md
├── mechanical_design.md
├── actuator_selection.md
├── electronics.md
├── power_system.md
├── kinematics.md
├── bill_of_materials.md
├── assembly.md
├── testing.md
└── v2_ai_roadmap.md

firmware/
software/
cad/
calculations/
```

Modify the structure if necessary.

---

# 20. IMPORTANT — NO SCOPE CREEP

This is probably the most important instruction.

I want a robot that I can **actually finish**.

Do NOT turn this into:

- A 6-DOF industrial arm
- A $500 robot
- A ROS project
- An autonomous research robot
- A precision CNC machine
- A complicated computer-vision system
- An over-engineered mechanical system

The project should feel like:

> **"An engineering student built a small, cheap, clever desktop robot arm using 3D printing and readily available electronics."**

Not:

> **"A startup spent six months developing an industrial robotic manipulator."**

If you find yourself adding a component or feature, ask:

**"Does V1 genuinely need this?"**

If not, leave it for V2 or omit it.

---

# 21. FINAL DESIGN REVIEW

Before generating the detailed design, provide me with:

1. Recommended robot architecture
2. Recommended 3 DOFs
3. Recommended arm dimensions
4. Recommended servo for each joint
5. SG90 vs MG90S gripper decision
6. Estimated payload
7. Estimated workspace
8. Servo torque calculations
9. Base stability calculation
10. Recommended microcontroller
11. Recommended power system
12. Purchase BOM
13. University-sourced BOM
14. Estimated total personal cost
15. Mechanical design concept
16. Electronics architecture
17. Software architecture
18. Kinematics approach
19. Main design risks
20. V1 → V2 roadmap
21. Realistic build timeline

**Do not begin with implementation before presenting the proposed architecture and cost.**

If the proposed design exceeds **CAD $100**, redesign it.

The guiding principle is:

> **Simple system, thoughtful engineering, actually buildable.**

I want to learn robotics, mechanical design, electronics, embedded programming, kinematics, and eventually AI integration — but I want to do it by building a small project that I can realistically finish.

---

# 22. FALLBACK V1 CONFIGURATIONS

Design V1 around a **primary configuration**, but also define fallback configurations in case certain components are unavailable, too expensive, or don't provide enough torque.

The purpose of these fallbacks is to prevent the project from getting stuck because of one component.

Do NOT immediately jump to a more expensive configuration. Always try the cheapest viable option first.

## Configuration A — Ultra-Budget

**Target personal cost: CAD $50–60**

Use the cheapest reasonable components.

Example architecture:

- 3 × inexpensive hobby servos
- 1 × SG90 or MG90S gripper servo
- Arduino Nano / Pico / similar
- Basic 5–6 V servo power supply
- 3D-printed PLA/PETG structure
- Minimal bearings/hardware

Target:

- Lightweight arm
- ~200–300 mm reach
- Very light payload
- Simple two-finger gripper

This configuration should be considered the **minimum viable robot**.

The goal is simply:

> It moves reliably, the joints work, and it can pick up lightweight objects.

Do not expect high precision or large payload capacity.

---

## Configuration B — Recommended V1

**Target personal cost: CAD $60–80**

Use slightly stronger actuators where they provide meaningful benefits.

Potential architecture:

- Stronger servo for shoulder
- Medium servo for elbow
- Smaller/medium servo for base
- MG90S for gripper
- Arduino Nano / ESP32 / Pico
- Proper external servo power
- PLA/PETG printed structure
- Cheap bearings/bushings where useful

Target:

- ~250–350 mm reach
- Lightweight desk-object manipulation
- Better repeatability
- Better structural rigidity
- Enough torque to make the arm useful rather than merely demonstrational

This should be the **default design target** if the budget allows it.

---

## Configuration C — University-Sourced

**Target personal cost: CAD $50–70 or less**

Take advantage of the university resources I have access to.

If suitable components are available through the university, use them instead of purchasing new components.

Potentially use:

- Existing servos
- Existing microcontroller
- Existing bearings
- Existing power supply
- Existing wiring/connectors
- Existing fasteners
- Existing sensors

However, do not use an unusual component simply because it is available.

The component still needs to be appropriate for the design.

Clearly document:

**University-sourced component → equivalent inexpensive purchased component**

so that the design remains reproducible.

---

## Configuration D — Stronger V1

**Target maximum personal cost: CAD $80–100**

Only use this configuration if the torque calculations show that the cheaper configurations cannot provide adequate performance.

Possible changes:

- Stronger digital servo for shoulder
- Stronger digital servo for elbow
- Better base servo
- MG90S gripper
- Slightly stronger printed structural components
- Better bearings at high-load joints

The purpose of this configuration is **not to increase payload dramatically**.

It exists to provide additional torque margin and improve reliability.

Do not add unnecessary features just because the budget permits them.

---

# 23. FALLBACK DECISION TREE

Use this decision process:

```text
                     START
                       │
                       ▼
              Can the cheapest
              configuration meet
               torque requirements?
                    /     \
                  YES      NO
                   │        │
                   ▼        ▼
             CONFIG A   Can university
                        components solve it?
                          /      \
                        YES      NO
                         │        │
                         ▼        ▼
                      CONFIG C   CONFIG B
                                  │
                                  ▼
                         Still insufficient?
                               /     \
                             NO       YES
                              │         │
                              ▼         ▼
                           CONFIG B   CONFIG D
```

The actual decision should be based on the torque calculations and component availability rather than arbitrary preference.

---

# 24. COMPONENT FALLBACKS

For each critical component, define at least one fallback.

Example:

### Shoulder Servo

Primary:
- Recommended servo

Fallback 1:
- Cheaper servo if payload/reach is reduced

Fallback 2:
- University-sourced equivalent

Fallback 3:
- Stronger servo if torque margin is insufficient

Do the same for:

- Base servo
- Elbow servo
- Gripper servo
- Microcontroller
- Power supply
- Bearings
- Fasteners

---

# 25. GEOMETRY FALLBACK

The arm dimensions should also have a fallback.

If the selected servos cannot handle the initial arm geometry:

### First solution:
Reduce payload.

### Second solution:
Reduce arm/link length.

### Third solution:
Reduce printed-part mass.

### Fourth solution:
Use a stronger servo.

Do NOT immediately increase the budget.

For example, if a 350 mm arm requires an expensive servo but a 275 mm arm works with a $10 servo, prefer the shorter arm for V1.

---

# 26. GRIPPER FALLBACK

Primary:

**MG90S + simple 3D-printed two-finger gripper**

Fallback:

**SG90 + lighter/smaller gripper**

If neither is available:

Use another small hobby servo with similar torque and dimensions.

The gripper should remain mechanically simple.

---

# 27. V1 CONFIGURATION COMPARISON

At the end of the design analysis, provide a table like:

| | Config A | Config B | Config C | Config D |
|---|---|---|---|---|
| Approx. cost | $50–60 | $60–80 | $50–70 | $80–100 |
| Reach | | | | |
| Payload | | | | |
| Base servo | | | | |
| Shoulder servo | | | | |
| Elbow servo | | | | |
| Gripper | | | | |
| Controller | | | | |
| University components | Minimal | Minimal | High | Optional |
| Difficulty | | | | |
| Main advantage | | | | |

Do not rank these configurations as "best" or "worst."

Instead, explain the **trade-offs** and what conditions would make each configuration appropriate.

The default starting point should be the **lowest-cost configuration that satisfies the engineering requirements**.

---

# 28. IMPORTANT

Do not design four completely different robots.

All fallback configurations should share as much as possible:

- Same general arm geometry
- Same SolidWorks assembly structure
- Same mounting strategy
- Same software
- Same control architecture
- Same gripper interface where possible

Ideally, changing from one configuration to another should require only swapping:

- Servos
- Power supply
- Minor mounting adapters

This way I can start with the cheapest configuration and upgrade individual components later without redesigning the entire robot.

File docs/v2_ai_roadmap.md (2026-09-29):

# V2 — AI tabletop assistant roadmap

Nothing here gets built now. It's recorded so V1's decisions don't
accidentally close a door V2 needs open.

This covers two decoupled tracks: the AI/vision stages below (2.1–2.4,
added on top of an *unchanged* V1 chassis — the original scope), and a
separate payload/actuator upgrade path (§Payload upgrade path) that's a
different axis entirely and not implied by "V2."

## Stages

| Stage | Adds | Cost | Touches V1? |
|---|---|---:|---|
| 2.1 Eyes | USB webcam on a printed overhead mast, bolted to the base plate | $0–15 | One new printed part. No electronics change. |
| 2.2 Desk-plane calibration | Four-point homography: camera pixels → desk coordinates | $0 | New module. This is the whole of the coordinate problem — a desk is flat, so a 3×3 matrix is all that's needed. No depth camera, no stereo. |
| 2.3 Detection | YOLO or a colour/contour detector returning object centroids | $0 | New module, feeds (u, v) into 2.2. |
| 2.4 Agent | A language model with `arm.pickup()` / `arm.place()` exposed as tools | $0 | Nothing — the agent calls the same six methods the CLI calls. |

## The three decisions V1 makes on V2's behalf

Each costs nothing now and would be expensive to retrofit later:

1. **The PC holds the intelligence, the MCU holds the safety.** Joint limits
   and slew limiting live in firmware (`docs/electronics.md`), so the agent
   physically cannot exceed a joint limit no matter what it decides to do.
2. **The arm's public API is Cartesian** (`arm.move_to(x, y, z)`,
   `arm.pickup(x, y, z)`, `arm.place(x, y, z)` — see `software/robot/arm.py`).
   Vision output plugs straight into it; nothing about the API needs to
   change when a camera is added.
3. **The base plate has mounting provision for a camera mast** (see
   `cad/README.md`), so the camera-to-robot transform can be calibrated once
   and stays valid — the mast doesn't move relative to the base yaw axis.

Incidental to the V1→ESP32 swap (`docs/electronics.md`): the controller now
has Wi-Fi/BT on board, unused in V1 and not a reason to change anything
here — the PC↔arm link stays USB serial. If V2 ever wants the arm
untethered, that option now exists without a controller swap; it is not
otherwise part of this plan.

## Payload upgrade path — gearmotors + encoders

A different axis from 2.1–2.4 above: actuation/payload, not perception.
Not part of "V2" as the original brief scoped it (camera/vision/AI on an
*unchanged* chassis) — recorded here as its own track so it isn't implied
by, or confused with, the AI stages.

**What changes vs V1:**

- **Actuator.** Hobby servo (closed-loop internally, absolute position at
  power-on) → DC gearmotor + planetary gearbox (open-loop mechanically,
  needs external position feedback). This is the whole reason it's a
  bigger step than it looks: servos hide their control loop from you,
  gearmotors don't.
- **Firmware.** Needs an encoder-read + PID position loop per joint,
  replacing the current angle → microsecond → `Servo`/`ESP32Servo` mapping.
  Genuinely new firmware, not a config change.
- **Homing.** Motors don't know where they are at power-on the way servos
  do. Needs a homing routine (limit switch or encoder index pulse) — this
  reverses the "servos are absolute-position devices, so we don't need
  limit switches" decision in `docs/electronics.md`. A motor-based build
  does need them.
- **Driver hardware.** PWM-to-servo-signal wiring is replaced by a motor
  driver (H-bridge) per joint — new electronics, and the current budget in
  `docs/power_system.md` needs redoing from scratch; gearmotors under load
  pull meaningfully more than the current 1.8 A design case.
- **Mechanical.** Gearmotors + planetary stages are much bigger and
  heavier than micro servos — a new mechanical design, not a bracket swap.
  Mass budget, torque calcs, and print-orientation rules all get redone
  for the new actuator envelope.
- **Protocol.** The low-level serial commands (`J`, `US`) are
  servo-microsecond-specific and would need a new command set (target
  angle/velocity through the PID loop).

**What doesn't change:** `robot.arm.Arm`'s six public calls
(`home`, `move_joints`, `move_to`, `grip`, `pickup`, `place`) and the
Cartesian API contract — that boundary was deliberately drawn
actuator-agnostic (see "The three decisions V1 makes on V2's behalf"
above), so this upgrade plugs into the same PC-side software. The
"firmware owns safety, PC owns intelligence" split also holds, though the
safety firmware itself gets substantially more complex.

**Not scoped or budgeted yet.** Servo/motor selection, gear ratio, encoder
choice, driver IC, and a new power budget all need their own design
review before this is a real plan — the same gate V1 went through in
`docs/requirements.md`, not an assumption to build against yet.

## Worked example

"Pick up my screwdriver and put it beside my laptop" resolves to:

```
detect (2.3) → centroid (u, v) → homography (2.2) → (x, y, z)
  → arm.pickup(x, y, z)                                  [unchanged from V1]
  → agent picks a target (x', y', z') beside the laptop
  → arm.place(x', y', z')                                [unchanged from V1]
```

Every step after the homography is V1 code that already works. V2's actual
new code is stages 2.1–2.3; stage 2.4 is wiring, not development — see
`software/robot/arm.py` for the exact six calls it's built to expose.

## Explicitly out of scope, even for V2 planning purposes

Per brief §20/§16 — do not let V2 planning smuggle these back in:

- ROS or any robotics middleware/message bus
- A depth camera or stereo rig — the desk is flat; homography is enough
- Multi-object tracking, grasp planning, or anything resembling
  manipulation research
- Autonomous operation without a human-issued command

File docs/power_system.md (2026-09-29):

# Power system

## Current budget

| Servo | Qty | Idle | Moving | Stall |
|---|---:|---:|---:|---:|
| MG996R | 2 | 0.17 A | 0.6–0.9 A | 2.5 A |
| MG90S | 2 | 0.08 A | 0.2–0.4 A | 0.7 A |
| SG90 | 1 | 0.06 A | 0.2 A | 0.65 A |
| **Rail total** | 5 | **0.56 A** | **1.2–1.8 A** | **7.05 A** |

The 7.05 A all-stall figure isn't a design case — it requires every joint
jammed simultaneously, which on a desk arm means something has already gone
wrong. The design case is **1.8 A continuous, ~3.5 A transient** at
direction reversals.

## Supply specification

**6.0 V, 3 A regulated (18 W), barrel jack, 3 A fuse.**

6.0 V because MG996R torque is quoted at 6 V; at 5 V you lose ~15% and
shoulder safety factor falls from 2.44 to 2.08 (see
`docs/actuator_selection.md`). The 4.8–6.6 V window covers all five servos.

Bulk capacitance: 2 × 1000 µF across the rail, placed physically at the
servo headers (not just at the supply) to actually damp the local transient.

```
Capacitor hold time: C·ΔV/I = 2000 µF × 0.5 V / 2 A = 0.5 ms
```

Be honest about what the capacitors do: two thousand microfarads hold a 2 A
surge for half a millisecond before the rail sags half a volt. They kill the
switching spike that would otherwise reset the MCU; they are **not** a
substitute for a supply that can actually source the current. Don't let a
capacitor talk you into a 1 A adapter.

## Sourcing options

| Option | Notes |
|---|---|
| **Bench supply** (use for bring-up) | Set 6.0 V with a 3 A current limit. The ammeter is genuinely diagnostic — a joint drawing 1.5 A while holding still is a joint fighting its own mechanical limit, and you'll see it before you smell it. Use for the whole of Phase 7 (testing). |
| **6 V 3 A adapter (primary purchase)** | ~$14. Doubles as ballast on the base plate — see `docs/mechanical_design.md` / stability calc in the planning guide §6. |
| **5 V 3 A phone charger (fallback)** | Free if you already own a USB-C PD or old 5 V/3 A brick. Costs ~15% of torque; shoulder SF 2.08 — acceptable, not comfortable. |
| **4×AA batteries (rejected)** | Nominal voltage is fine — 4 fresh alkaline cells land around 6.4 V, inside the 4.8–6.6 V window. The problem is internal resistance, not voltage: alkaline AAs run ~0.15–0.3 Ω each, so ~0.6–1.2 Ω for the pack. At the 1.8 A design-case draw that's 1.1–2.2 V of sag before the 3.5 A transient case makes it worse — the same failure mode as the capacitor note above, a source that can't hold voltage under real load. Expect soft/inconsistent moves or brownouts, not a clean fault. NiMH cells have lower internal resistance and are the better chemistry *if* a battery pack is ever used for real, but even then treat it as good for a single-joint bench check, not for running the assembled arm. |

## Three rules, each of which has ended someone's project

1. **Never feed the servo rail from the ESP32's 5V/VIN pin or USB.** That
   pin sits upstream of the board's own 3.3 V logic regulator and reflects
   whatever the USB port can source — typically 500 mA; five servos will
   brown it out and reset the board mid-move.
2. **Servo ground and ESP32 ground must be joined.** Otherwise the PWM has no
   common reference and servos twitch randomly.
3. **No 7.4 V LiPo direct to the rail.** It will destroy the MG90S and SG90
   within minutes — they're rated to 6.6 V, not 7.4 V.

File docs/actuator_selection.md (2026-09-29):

# Actuator selection

## Method

Static gravity-holding torque at the worst-case pose (fully extended,
horizontal — also the normal working pose for a desk arm reaching across the
table). Dynamic/inertial terms are small at the speeds this arm moves at
(under 10% of the gravity term at the 60°/s slew limit firmware enforces) and
are absorbed by the safety-factor floor rather than modelled explicitly.

Target safety factor: **≥ 2.0**, evaluated at 6.0 V rated torque. This isn't
extra conservatism on top of a passing design — hobby servos publish *stall*
torque, and a servo held near stall runs hot and wears out fast. SF 2.0 is
roughly where a servo can hold a static pose indefinitely without cooking.

## Mass budget (inputs to the torque calc)

Horizontal distance from the shoulder axis, arm fully extended — the
worst case for every load in the chain:

| Item | Mass | Distance | Moment (g·mm) |
|---|---:|---:|---:|
| Upper-arm link pair + spacers | 30 g | 60 mm | 1,800 |
| Elbow servo (MG996R) + bracket | 65 g | 120 mm | 7,800 |
| Forearm link pair + spacers | 25 g | 180 mm | 4,500 |
| Wrist servo (SG90) + bracket | 17 g | 250 mm | 4,250 |
| Gripper assembly (MG90S + jaws) | 32 g | 285 mm | 9,120 |
| Design payload | 55 g | 320 mm | 17,600 |
| **Moving assembly total** | **224 g** | CoM 201 mm | **45,070 g·mm** |

Below the shoulder (drives base stability, not shoulder torque): base plate
100 g, column + turret 60 g, base servo 14 g, shoulder servo 55 g, hardware
40 g → **269 g**.

The elbow servo alone is 29% of the moving mass, at the point in the chain
where moving it costs the most shoulder torque. If shoulder margin ever
becomes a real problem, relocating that servo to the turret behind a
linkage is the highest-leverage fix available (~1.4 kg·cm) — noted here,
not implemented in V1.

## Torque calculations

```
Shoulder, arm horizontal at full extension:
  τ₁ = g · Σ(mᵢdᵢ) = 9.81 × 0.04507 kg·m = 0.442 N·m = 4.51 kg·cm

Elbow, moments about the elbow axis:
  τ₂ = 9.81 × (0.025×0.060 + 0.017×0.130 + 0.032×0.165 + 0.055×0.200)
     = 9.81 × 0.01999 = 0.196 N·m = 2.00 kg·cm

Base yaw — no gravity term, inertia + bearing drag only:
  I ≈ 0.0056 kg·m², α = 3.5 rad/s² → τ = 0.020 N·m, + drag ≈ 0.30 kg·cm
```

These are reproduced (and checkable) in `calculations/engineering_calcs.py`.

## Servo table

| Joint | Servo | Required | Target ×2 | Rated @6V | Actual SF | Verdict |
|---|---|---:|---:|---:|---:|---|
| Base | MG90S | 0.30 | 0.60 | 2.20 | 7.3 | ample |
| **Shoulder** | **MG996R** | **4.51** | **9.02** | **11.00** | **2.44** | sizing joint |
| Elbow | MG996R | 2.00 | 4.00 | 11.00 | 5.50 | pass |
| Wrist (slave) | SG90 | 0.58 | 1.17 | 1.80 | 3.08 | pass |
| Gripper | MG90S | 0.82 | 1.64 | 2.20 | 2.7 | pass |

All kg·cm, generic MG996R/MG90S/SG90 published specs at 6.0 V. On a 5 V
supply the MG996R drops to ~9.4 kg·cm and shoulder SF falls to 2.08 — still
acceptable, which is why a 5 V/3 A phone charger is a legitimate power
fallback (see `docs/power_system.md`).

**Why the elbow is over-specified (5.50), deliberately:** it needs 2.00
kg·cm, so at SF 2 it needs 4.0. The MG90S tops out at 2.2 and fails. The
next rung up, an MG92B at 3.5 kg·cm (~$8), still gives only SF 1.75 — and
costs more than an MG996R. There's nothing worth buying between them, so the
MG996R wins by default and the extra margin is free.

## Gripper: SG90 vs MG90S

Required clamp force for a 55 g object against gravity, μ = 0.5 (rubber pad,
conservative): `mg / 2μ = 0.54 N`. Design target: **4 N per jaw** — about 7×
the physics minimum, because real grips are off-centre and objects get
bumped.

```
Jaw tip force        F = 4.0 N at 30 mm from the jaw pivot
Jaw pivot torque      0.12 N·m
Drive reduction       1.5:1 (12 mm servo crank → 18 mm jaw crank)
Servo torque          0.080 N·m = 0.82 kg·cm

MG90S @ 6 V   2.2 kg·cm → SF 2.7
SG90  @ 4.8 V 1.6 kg·cm → SF 2.0
```

**Both pass on torque.** The decision is about what happens the twentieth
time the gripper closes on something it can't close on:

| | SG90 | MG90S (chosen) |
|---|---|---|
| Mass / cost | 9 g / ~$2 | 13.4 g / ~$6 |
| Gears | Nylon — strips on a hard stall or side impact | Metal — survives stalls and knocks |
| Footprint | 22.8 × 12.2 × 22.5 mm, 32 mm hole spacing | **Identical** — drop-in either way |

The identical footprint means the mount is one printed part regardless of
which servo goes in it. MG90S chosen; SG90 is the documented fallback if
gripper cost needs to drop (Configuration A).

**Mechanism:** two mirror-image printed jaws on M3 pins with meshed gear
sectors (module 1.5, ~10 teeth engaged) at their pivots. One servo drives one
jaw through a short link; the sectors force the other to mirror it — self
-centring, can't desync. Jaw faces carry a 90° V-groove (self-centres pens
and shafts) plus a glued rubber pad.

**Compliance matters more than gear material:** thin the last 12 mm of each
jaw to 1.6 mm so it flexes ~1 mm under load. One commanded "closed" angle
then grips a range of object sizes without ever driving the servo into a
hard stall — this detail does more for gripper longevity than metal vs.
nylon gears.

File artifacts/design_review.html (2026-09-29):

Design review — pre-build gate Rev A 3-DOF + gripper V1 scope only

# Desk Arm V1 Design Review

A 315 mm tabletop arm built from four hobby servos, twenty printed parts and about sixty dollars. Every number below is worked from a mass budget, not guessed.

Recommendation

Build Configuration B. Direct-drive revolute arm, L1 = L2 = 120 mm, MG996R at shoulder and elbow, MG90S at base and gripper, SG90 as a software-slaved wrist leveller, ESP32 over USB serial. Worst-case shoulder safety factor is 2.44. Configuration A is genuinely viable but only by shrinking the arm to 275 mm and the payload to 30 g — and it saves roughly $8. That trade is not worth taking. Configuration D is not required; the torque margins do not justify it.

Reach (TCP)

315mm from base axis

Design payload

55g at full reach

Shoulder SF

2.444.51 of 11.0 kg·cm

Tipping SF

2.26with 400 g ballast

Repeatability

±6mm, backlash-limited

Purchase cost

$59CAD, typical sourcing

01

## Recommended architecture

Serial revolute arm, the classic RRR shoulder–elbow chain on a rotating turret. Base yaw is the only vertical axis; shoulder and elbow work in a single vertical plane that the base sweeps around. That is the simplest structure that reaches every point on a desk, and the kinematics collapse to one trig problem you can write on an index card.

Axis | Type | Range | Actuator | Notes
1 — Base yaw | Revolute, vertical | −90° … +90° | MG90S | Turret rides on two 608ZZ so the servo carries torque only, never the overturning moment.
2 — Shoulder | Revolute, horizontal | 0° … 110° | MG996R | Highest-loaded joint in the machine. Sets the whole design.
3 — Elbow | Revolute, horizontal | −130° … 0° | MG996R | Elbow-up solution only; elbow-down collides with the table.
Wrist pitch slave | Revolute, horizontal | −120° … +30° | SG90 | Not a commanded DOF. Firmware drives it to −(θ₁+θ₂) so the jaws stay level in every pose.
Gripper | Two-finger, meshed sectors | 0 … 55 mm | MG90S | Symmetric self-centring jaws with V-grooves.

### Why a slaved wrist rather than a parallelogram linkage

A three-DOF positioner has exactly enough freedom to hit an (x, y, z) target and none left over — so gripper pitch is whatever the IK happens to produce, swinging roughly 30° across the workspace. Picking a pen off a desk with tilted jaws is miserable. There are three ways out:

### Twin parallelogram

Two four-bar linkages in series hold the jaws level with no extra servo, and move the elbow actuator down to the turret. Elegant, and it is what the EEZYbotARM does.

Cost: six more printed parts, twelve more pivot pins, and slop at every one of them. deferred

### SG90 slaved wrist chosen

One extra micro servo at the wrist, driven by firmware as a dependent axis. You still command three DOF; the fourth is computed, never exposed.

Cost: about $3 and 17 g at 250 mm — which drops shoulder SF from 2.57 to 2.44. Cheap for level jaws.

### Fixed bracket

Bolt the gripper on at a fixed 45°. Zero cost, zero parts, and it works if you always approach objects from the side.

Cost: pose-dependent jaw tilt. The right answer for Configuration A. fallback

All three bolt to the same 24 × 24 mm wrist mounting face on the forearm. You can start with the fixed bracket, add the SG90 later, and try the linkage after that without touching another part in the assembly.

02

## Geometry

Equal 120 mm links. Equal lengths make the printed parts nearly identical (one parametric sketch, two configurations), maximise the folded-to-extended ratio, and put the workspace boundary where you want it. Everything is sized from the torque budget in §04, not from a target that looked impressive.

Side elevation, 1 px = 1 mm, arm shown mid-stroke. The wrist stays level in every pose, which is why L₃ is a purely horizontal offset in the kinematics.

Parameter | Value | Rationale
Shoulder height h₀ | 75 mm | Enough for the elbow to fold without hitting the turret; low enough to keep the tipping moment down.
Upper arm L₁ | 120 mm | Torque-driven. 140 mm pushes shoulder SF below 2.1.
Forearm L₂ | 120 mm | Equal to L₁ — same printed profile, fully-folded pose reaches the base.
Wrist→TCP L₃ | 75 mm | Jaw depth plus clearance to grip a 30 mm object.
Max TCP reach | 315 mm | Within the 250–350 mm brief.
Max TCP height | 315 mm | Arm vertical. Overall envelope ~340 mm including the gripper.
Base footprint | 180 × 180 mm | Drives the tipping calculation in §06.
Jaw opening | 0–55 mm | Covers a pen through a small project box.

03

## Mass budget

Nothing else in this review is trustworthy unless this table is. Printed masses assume PLA at 1.24 g/cm³, 4 perimeters, 30% gyroid — the settings in §12. Servo masses are manufacturer figures. Distances are measured horizontally from the shoulder axis with the arm fully extended, which is the worst case for every load in the machine.

Item | Mass | Distance | Moment
Upper-arm link pair + spacers | 30 g | 60 mm | 1 800
Elbow servo (MG996R) + bracket | 65 g | 120 mm | 7 800
Forearm link pair + spacers | 25 g | 180 mm | 4 500
Wrist servo (SG90) + bracket | 17 g | 250 mm | 4 250
Gripper assembly (MG90S + jaws) | 32 g | 285 mm | 9 120
Design payload | 55 g | 320 mm | 17 600
Moving assembly | 224 g | CoM 201 mm | 45 070 g·mm

Below the shoulder, not carried by any joint: base plate 100 g, column and turret 60 g, base servo 14 g, shoulder servo 55 g, hardware 40 g — 269 g. That figure drives §06.

The elbow servo is 29% of the moving mass. It is the single heaviest thing the shoulder lifts, and it sits at exactly the point where moving it costs the most. If shoulder margin ever becomes a problem, relocating that servo to the turret behind a linkage is the highest-leverage change available — worth roughly 1.4 kg·cm.

04

## Joint torque and servo selection

Static gravity holding torque at the worst-case pose, which for a desk arm is also the working pose — fully extended, reaching for something at the far edge. Dynamic torque is small here: at the speeds this arm will move, inertial terms are under 10% of the gravity term, and the safety factor absorbs them.

// shoulder, arm horizontal at full extension τ₁ = g · Σ mᵢdᵢ = 9.81 × 0.04507 kg·m = 0.442 N·m = 4.51 kg·cm // elbow, moments taken about the elbow axis τ₂ = 9.81 × (0.025×0.060 + 0.017×0.130 + 0.032×0.165 + 0.055×0.200) = 9.81 × 0.01999 = 0.196 N·m = 2.00 kg·cm // base yaw — no gravity term; inertia + bearing drag only I ≈ 0.0056 kg·m², α = 3.5 rad/s² → τ = 0.020 N·m, +drag ≈ 0.30 kg·cm

Joint | Servo | Required | Target ×2 | Rated @6 V | Actual SF | Verdict
Base | MG90S | 0.30 | 0.60 | 2.20 | 7.3 | ample
Shoulder | MG996R | 4.51 | 9.02 | 11.00 | 2.44 | sizing joint
Elbow | MG996R | 2.00 | 4.00 | 11.00 | 5.50 | pass
Wrist (slave) | SG90 | 0.51 | 1.02 | 1.80 | 3.5 | pass
Gripper | MG90S | 0.82 | 1.64 | 2.20 | 2.7 | pass

All figures in kg·cm. Rated values are the common published specs for generic MG996R / MG90S / SG90 at 6.0 V. On a 5 V supply the MG996R drops to ~9.4 kg·cm and shoulder SF falls to 2.08 — still acceptable, which is why a 5 V phone charger is a legitimate power fallback.

### Why the elbow is over-specified, deliberately

An SF of 5.5 looks wasteful. It is not a choice — it is what the price ladder does. The elbow needs 2.00 kg·cm, so at SF 2 it needs 4.0. The MG90S tops out at 2.2 and fails. The next rung up is the MG92B at 3.5 kg·cm for about $8, which gives SF 1.75 — still short, and more expensive than an MG996R. There is nothing between them worth buying. The MG996R is the cheapest part that passes, so it wins by default and you get the margin for free.

A note on why the numbers are not tighter. Everything here is static holding torque with a stall-rated servo. Hobby servos publish stall torque, and running a servo anywhere near stall makes it hot, slow and short-lived. SF 2 is not conservatism — it is roughly the point at which an MG996R holds a pose indefinitely without cooking. Treat 2.0 as the floor, not a comfort margin.

05

## Gripper: SG90 vs MG90S

Required clamping force for a 55 g object against gravity, with a conservative friction coefficient of 0.5 on a rubber pad, is mg / 2μ = 0.54 N. The design targets 4 N per jaw — about seven times what the physics demands, because real grips are off-centre and objects get bumped.

jaw tip force F = 4.0 N at 30 mm from the jaw pivot jaw pivot torque 0.12 N·m drive reduction 1.5 : 1 (12 mm servo crank → 18 mm jaw crank) servo torque 0.080 N·m = 0.82 kg·cm MG90S @ 6 V 2.2 kg·cm → SF 2.7 SG90 @ 4.8 V 1.6 kg·cm → SF 2.0

Both pass on torque. The decision has nothing to do with torque. It is about what happens the twentieth time the gripper closes on something it cannot close on.

### SG90 — nylon gears

- 9 g, about $2
- Strips its output gear on a hard stall or a side impact. The gripper is the part of this robot most likely to receive both.
- Fine where load is predictable and light — which is exactly the wrist-levelling axis.

### MG90S — metal gears chosen

- 13.4 g, about $6
- Identical 22.8 × 12.2 × 22.5 mm body and 32 mm hole spacing — drop-in either way, so the mount is one part.
- Survives the stalls and knocks that kill an SG90. The extra $4 buys a part that does not become a consumable.

### Mechanism

Two mirror-image printed jaws on M3 pins, with meshed gear sectors at their pivots — module 1.5, roughly 10 teeth of engagement, which prints cleanly on a 0.4 mm nozzle. The servo drives one jaw through a short link; the sectors force the other to mirror it. Four printed parts, two pins, self-centring, and no way to get the jaws out of sync. Jaw faces carry a 90° V-groove so pens and screwdriver shafts centre themselves, plus a glued-on rubber pad.

Design the jaws to be compliant, not just strong. A hobby servo commanded to a "closed" angle it cannot reach will sit there drawing stall current until something gives. Thin the last 12 mm of each jaw to 1.6 mm so it flexes ~1 mm under load. One closed angle then grips a range of object sizes without the servo ever hard-stalling. This detail matters more than the gear material.

06

## Base stability

Tipping about the front edge of the base plate, arm fully extended, payload at maximum reach. The shoulder axis sits 10 mm forward of the base axis, so the moving CoM is 211 mm out.

// overturning, about an edge 90 mm from the base axis M_over = 0.224 × 9.81 × (0.211 − 0.090) = 0.266 N·m // restoring, base assembly only M_rest = 0.269 × 9.81 × 0.090 = 0.237 N·m → SF 0.89 TIPS // restoring, with 400 g of ballast in the base cavity M_rest = 0.669 × 9.81 × 0.090 = 0.591 N·m → SF 2.22 OK

The arm as-drawn tips over. This is the one result in the review that changes the design rather than confirming it, and it is easy to miss on paper because the arm only weighs 500 g total. A 224 g mass on a 211 mm lever beats a 269 g base on a 90 mm lever, and no amount of careful printing fixes that.

### Fix: ballast the base primary

Model a sealed 66 × 66 × 18 mm cavity into the base plate with a printed snap lid. Fill with M8 washers, sand, or a bag of spare screws. 400 g minimum, 500 g preferred. Costs nothing and lowers the CoM as well as raising the mass.

### Fix: park the supply on the plate

A 6 V 3 A brick weighs 150–250 g. Recess it into the base plate behind the column and it becomes free ballast plus shorter power leads. Counts toward the 400 g.

### Fix: clamp it down optional

Two 8 mm slots at the rear of the plate take a small C-clamp. Makes tipping structurally impossible and is worth having for fast moves, but it should not be the only thing keeping the arm upright.

Dynamic loading is worse than this calculation. Decelerating the arm at the end of a fast reach adds an inertial term the static analysis ignores. That is why the target is SF 2.2 and not 1.2 — and why V1 firmware slew-limits every joint to 60°/s.

07

## Workspace

Because the wrist holds the gripper level, the TCP envelope is a circle of radius L₁+L₂ = 240 mm centred not on the shoulder but on a point offset by L₃ — at (r, z) = (75, 75). Sweeping that profile through 180° of base rotation gives the usable volume.

Reachable TCP envelope in the vertical plane. The inner boundary is a software limit, not a kinematic one — with equal links the arm can fold to r = 0, but it would fold into its own turret first.

Bound | Value | Set by
Outer radius | 315 mm | Kinematic: L₁+L₂+L₃, reached only with the arm straight.
Practical outer radius | 290 mm | Software limit. The last 25 mm is a singularity where IK becomes ill-conditioned and tiny position errors demand huge joint changes.
Inner radius | 130 mm | Collision: the forearm would strike the turret and the base column.
Floor | z = 10 mm | Jaw tips clear the desk. Hard limit in firmware — the most likely way to break the arm is to drive it into the table.
Ceiling | z = 315 mm | Arm vertical.
Base sweep | ±90° | Cable wrap. A full 360° needs a slip ring, which V1 does not.

Usable desk area: an annular sector roughly 130–290 mm radius across 180° — about 0.09 m² of desktop, which is a comfortable arc in front of a keyboard.

08

## Kinematics

No DH tables, no Jacobians, no numerical solvers. The base rotation decouples completely, leaving a two-link planar problem with a closed-form solution — roughly forty lines of Python including the workspace checks.

### Forward

r = L₁·cosθ₁ + L₂·cos(θ₁+θ₂) + L₃ z = h₀ + L₁·sinθ₁ + L₂·sin(θ₁+θ₂) x = r·cosθ₀ y = r·sinθ₀

L₃ adds directly to r with no trig term — that is the payoff from the levelled wrist. Without it, L₃ would carry a cos(θ₁+θ₂+θ₃) factor and the inverse problem stops being closed-form.

### Inverse

θ₀ = atan2(y, x) r′ = √(x²+y²) − L₃ // wrist-pivot radius z′ = z − h₀ D = (r′² + z′² − L₁² − L₂²) / (2·L₁·L₂) // |D| > 1 → target is unreachable. Check before acos(). θ₂ = −acos(D) // negative root = elbow-up θ₁ = atan2(z′, r′) − atan2(L₂·sinθ₂, L₁ + L₂·cosθ₂) θ₃ = −(θ₁ + θ₂) // slaved wrist, jaws level

The two acos roots are elbow-up and elbow-down. Elbow-down puts the joint below the table on nearly every desk-height target, so the solver takes the negative root unconditionally and never has to choose.

### Validation, in order, before anything moves

1. Reachability — |D| ≤ 1 and 130 ≤ √(x²+y²) ≤ 290.
2. Joint limits — every θ inside its mechanical range from §01.
3. Table clearance — z ≥ 10 mm, and the elbow itself above the table, which the elbow-up choice does not guarantee near the inner boundary.
4. Path check — for a Cartesian move, interpolate 20 waypoints and validate each. A straight line between two legal poses can pass through an illegal one.

The accuracy limit is backlash, not mathematics. An MG996R has 1–2° of gear lash plus potentiometer deadband. At a 240 mm lever, 1.5° is 6 mm at the gripper. Expect ±5–8 mm repeatability and design around it: approach every target from the same direction so the lash is always taken up the same way, and let the 55 mm jaw opening absorb the rest. No amount of IK precision buys back a millimetre of this.

09

## Electronics

PC ──USB──▶ ESP32 ──────5 × PWM signal──▶ servos │ ▲ └──── GND ═══════ common ══════╪═══ GND │ 6 V 3 A supply ──fuse──┬── 2 × 1000 µF ────────┘ └── V+ rail to all five servos

ESP32 — revised from an original Arduino Nano choice. The Nano's edge was native 5 V logic: hobby servos want a 5 V pulse, and a 3.3 V board introduces a question with no clean answer on paper — some servos latch reliably on 3.3 V, some jitter, and you find out after assembly. In practice the SG90/MG90S/MG996R family used here decodes PWM through an analog RC input stage that a 3.3 V high clears — a well-worn combination, not a gamble. Test each servo before final assembly; the documented fallback for a unit that jitters is a 74HCT125/74AHCT125 level shifter (~$1, one chip covers all five signal lines), not a controller change. In exchange: a dual-core chip with far more flash/RAM/GPIO than this project needs, a similar street price to the Nano, and Wi-Fi/BT already on board if V2 ever wants the arm untethered (unused in V1 either way — the PC is on the other end of a USB cable regardless). Requires the ESP32Servo library in place of the stock Servo.h; same attach()/writeMicroseconds() API, backed by the chip's LEDC PWM peripheral instead of a hardware timer.

Board | Cost | Logic | Assessment
ESP32 DevKit chosen | $12 | 3.3 V | ESP32Servo library, USB-serial via onboard CP2102/CH340 — install its driver before you need it. Test 3.3 V servo latching per-unit; level-shifter fallback above.
Arduino Nano | $9 | 5 V | Native servo levels, no latching question, stock Servo.h. The straightforward fallback if an ESP32 isn't available or a servo won't latch cleanly at 3.3 V.
Arduino Uno | — | 5 V | Electrically identical to the Nano, bulkier. Take this if the lab has one.
Raspberry Pi Pico | $7 | 3.3 V | Better PWM hardware, cheaper, MicroPython. Same 3.3 V latching consideration as the ESP32.

### Deliberately not included

### PCA9685 driver board

Five servos fit on five ESP32 GPIOs with the ESP32Servo library. The board solves a problem — running out of timers — that starts at about twelve servos. $6 and a whole I²C bus for nothing. skipped

### Encoders and current sensing

Hobby servos have no position feedback path to the MCU; adding external encoders means closing a loop the servo already closes internally. Real value, wrong project. skipped

### Limit switches

Servos are absolute-position devices — they know where they are at power-on. Homing switches solve a stepper problem this arm does not have. skipped

Assembly is a small piece of perfboard on the base plate: five 3-pin servo headers, a barrel jack, the bulk capacitors, a fuse, and jumper wires to the ESP32's GPIO/GND header pins. Under an hour of soldering. Full pin-out: docs/wiring_diagram.svg.

10

## Power

Servo | Qty | Idle | Moving | Stall
MG996R | 2 | 0.17 A | 0.6–0.9 A | 2.5 A
MG90S | 2 | 0.08 A | 0.2–0.4 A | 0.7 A
SG90 | 1 | 0.06 A | 0.2 A | 0.65 A
Rail total | 5 | 0.56 A | 1.2–1.8 A | 7.05 A

The 7.05 A all-stall figure is not a design case — it requires every joint to be jammed simultaneously, which on a desk arm means something has already gone badly wrong. The design case is 1.8 A continuous with ~3.5 A transients at direction reversals.

Specification: 6.0 V, 3 A regulated (18 W), barrel jack, 3 A fuse 6.0 V because MG996R torque is quoted at 6 V; at 5 V you lose 15% and shoulder SF falls from 2.44 to 2.08. The 4.8–6.6 V window covers all five servos. Bulk capacitance: 2 × 1000 µF across the rail, physically at the servo headers.

Be honest about what the capacitors do. C·ΔV/I = 2000µF × 0.5V / 2A = 0.5 ms. Two thousand microfarads hold a 2 A surge for half a millisecond before the rail sags half a volt. They kill the switching spike that resets the MCU; they are not a substitute for a supply that can actually source the current. Do not let a capacitor talk you into a 1 A adapter.

### Bench supply use for bring-up

Set 6.0 V with a 3 A current limit. The ammeter is genuinely diagnostic: a joint drawing 1.5 A while holding still is a joint fighting its own mechanical limit, and you will see it before you smell it. Use this for the whole of Phase 7.

### 6 V 3 A adapter primary

About $14. Doubles as ballast on the base plate. Buy one with a real current rating, not an optimistic one.

### 5 V 3 A phone charger fallback

Free if you own a USB-C PD or old 5 V/3 A brick. Costs 15% of the torque. Shoulder SF 2.08 — acceptable, not comfortable.

Three rules, each of which has destroyed someone's project.
1. Never feed the servo rail from the ESP32's 5V/VIN pin or USB. That pin sits upstream of the board's own 3.3 V logic regulator and reflects whatever the USB port can source (typically ~500 mA); five servos will brown it out and reset the board mid-move.
2. Servo ground and ESP32 ground must be joined, or the PWM has no reference and the servos twitch randomly.
3. No 7.4 V LiPo direct to the rail. It will destroy the MG90S and SG90 within minutes.

11

## Software architecture

The split is deliberate: the firmware owns safety, the PC owns intelligence. Anything that protects the hardware lives on the ESP32 and cannot be bypassed by a buggy Python script or, later, by a confused AI agent. Everything else lives on the PC where it is easy to change.

firmware/arm_firmware/ // ESP32 (Arduino C++) — the safety layer arm_firmware.ino serial parser, 50 Hz update loop limits.h per-joint µs bounds — hard clamp, no override slew.h 60°/s rate limiter, so nothing ever slams software/robot/ // Python — the thinking layer config.py link lengths, calibration, limits (one file to tune) transport.py serial port, line protocol, timeouts, retries kinematics.py fk(), ik(), reachable(), path_safe() trajectory.py eased interpolation between poses arm.py class Arm — THE public API software/cli.py interactive shell software/sequences.py demo routines // V2 adds here and nowhere else: software/vision/ camera, detector, desk-plane homography software/agent/ natural language → calls to arm.py

### Serial protocol

ASCII, line-oriented, one command per line, every command answered. Debuggable from a serial monitor with no tooling, which matters enormously on the first evening the arm does not move.

Command | Reply | Purpose
PING | OK ARM v1 | Port identification and liveness.
J <base> <sh> <el> | OK | ERR LIMIT <joint> | Absolute joint angles in degrees. Wrist follows automatically.
G <0-100> | OK | Gripper, 0 closed to 100 open.
US <ch> <µs> | OK | ERR RANGE | Raw pulse width. Calibration only — still bounded.
HOME | OK | Slew to the safe folded pose.
STOP | OK | Freeze at the current position.
REL | OK | Detach all servos. Kills holding buzz and lets you move the arm by hand.
STAT | <angles> <µs> | Current commanded state.

### The one interface that matters

arm.home() arm.move_joints(base, shoulder, elbow) arm.move_to(x, y, z) // Cartesian, validated, interpolated arm.grip(percent) arm.pickup(x, y, z) // approach above → descend → close → lift arm.place(x, y, z)

This is the V1→V2 contract. In V2 the agent does not get its own motion code, its own limits, or its own IK — it calls exactly these six methods. Vision produces an (x, y, z); the agent picks which one; arm.py is unchanged. If V2 ever needs to modify arm.py to work, the V1 API was designed wrong.

No ROS. No behaviour trees. No message bus. A 300 mm desk arm with five servos does not have a software problem that a Python class cannot solve, and every framework added here is a week not spent making the arm work.

12

## Mechanical design and printing

Roughly fourteen unique parts, twenty printed pieces, about 300 g of filament and 18–22 hours of print time. The links are twin side plates on printed spacers — a box section that is stiff in bending, easy to print flat with no supports, and puts every bolt in double shear.

### Material assignment

Part | Material | Why
Base plate, column, turret | PLA | Stiffness and flatness. Nothing here is impact-loaded.
Upper arm, forearm links | PLA | E ≈ 3.5 GPa vs PETG's 2.0 — 75% stiffer for the same section. Deflection is what matters in a link.
Shoulder and elbow brackets | PETG | Highest bending stress in the machine, and bending is where poor layer adhesion shows up. PETG's interlayer strength is worth the small stiffness loss.
Servo horn adapters | PETG | Small, bolted, and loaded in a direction that wants to peel layers apart. The one place PETG is not optional.
Gripper jaws | PETG | Designed to flex, and first to be dropped. PLA would snap at the compliant section.
Spacers, clips, tray | PLA | Unloaded. Print in whatever is on the machine.

Print settings throughout: 0.4 mm nozzle, 0.2 mm layers, 4 perimeters, 30% gyroid, 5 top/bottom. Perimeter count dominates strength in a thin printed part — four walls and 20% infill beats two walls and 60% every time, and weighs less.

### Layer orientation — the three rules that decide whether this works

1. Print brackets flat, never standing up. A shoulder bracket printed upright has its layer planes perpendicular to the bending stress, so the load tries to peel the layers apart and the part fails at roughly 40–60% of its in-plane strength. Printed flat, the same stress runs along continuous extrusions.
2. Every bolt hole has its axis normal to the build plate. Bolts then clamp across layers in compression, which printed plastic handles well, rather than trying to split them.
3. Never print a servo spline. A printed 25-tooth spline will round off — not might, will. Bolt the metal horn that came with the servo to the printed part with two or three M2 screws and let the horn take the torque. most common failure mode in printed arms

### Where SolidWorks Simulation actually earns its time

### Worth running 2 studies

- Shoulder bracket — 0.44 N·m through a bolted interface with a stress concentration at the servo cutout. The one part where intuition is unreliable.
- Upper arm link — check the elbow-servo pocket. Expect the answer to be "add a 3 mm fillet."

### Not worth running

- Everything else. The hand calculation below already answers the question.
- Use orthotropic properties if you run it at all, and treat the result as a comparison between two designs rather than a number.

// upper-arm tip deflection, 1.3 N at 120 mm, twin 20 × 3 mm plates I = 2 × (3 × 20³)/12 = 4000 mm⁴ δ = FL³/(3EI) = 1.3 × 120³ / (3 × 2500 × 4000) = 0.075 mm

Seventy-five microns. The structure is eighty times stiffer than the servo backlash it is bolted to. Do not thicken these links. Every gram added to the arm buys nothing measurable and costs shoulder safety factor directly — this is the part of the project where over-engineering makes the robot objectively worse.

### Parametric strategy for SolidWorks

- One global variable file driving L1, L2, L3, h0, plate thickness and pin diameter across every part.
- A servo-pocket library feature with a design table holding two rows — standard (40.7×19.7×42.9, 49.5 mm holes) and micro (22.8×12.2×22.5, 32 mm holes). Every mount references it, so swapping an MG996R for an MG90S is a configuration change, not a redesign. This is what makes Configurations A through D one robot instead of four.
- Assembly mated to reference planes and axes, never face-to-face between links. Change L1 and the assembly rebuilds instead of erroring.
- Configurations: Config-A-Short (L2 = 80) and Config-B-Standard (L2 = 120) from the same files.
- 0.2 mm clearance on every pin and pocket. Print a tolerance coupon first and adjust once — it saves a reprint of every part.

13

## Bill of materials

Prices are CAD, estimated from typical Amazon.ca listings. AliExpress runs roughly 40% cheaper with a three-week wait — worth it for the servos if you are not in a hurry, not worth splitting an order over.

### BOM A — purchase

Item | Qty | Cost | Uni? | Note
MG996R servo | 2 | $17 | unlikely | Shoulder, elbow. 2-pack; a 4-pack at $26 buys spares, and you will want one.
MG90S servo | 2 | $13 | maybe | Base, gripper.
SG90 servo | 1 | $3 | likely | Wrist leveller. Lab drawers are full of these.
6 V 3 A adapter + jack | 1 | $14 | likely | Bench supply substitutes entirely.
ESP32 DevKit (CP2102/CH340) | 1 | $12 | maybe | A Nano works as a $9 fallback — see §09.
1000 µF 16 V electrolytic | 2 | $3 | very likely | Any parts bin has these.
608ZZ bearing | 2 | $4 | likely | From a 10-pack. Or a dead skateboard.
M3 screw / nyloc assortment | 1 kit | $11 | very likely | M3×10/12/16/25. Workshop stock.
Dupont wire + perfboard | 1 | $8 | very likely | Lab stock.
PLA + PETG filament | ~300 g | $8 | likely | Share of a $25 spool.
Buy absolutely everything | | $93 | under the $100 ceiling

### BOM B — university-sourced, with purchased equivalents

Component | University alternative | Saves | Substitution risk
Microcontroller | Any ESP32 dev board in the lab, or a Nano/Uno/Mega/Pico fallback | $12 | low — confirm servo signal quality on whichever board turns up
Power supply | Bench PSU at 6.0 V / 3 A limit | $14 | none — better than the adapter for testing
Fasteners | Workshop M3 stock | $11 | none
Wiring, headers, perfboard | Electronics lab stock | $8 | none
Bearings | Mechanism-lab 608 or 625 stock | $4 | low — 625ZZ works with a bore change
Filament | Makerspace PLA / PETG | $8 | none
Capacitors | Any parts bin | $3 | none
Micro servos | SG90 / MG90S from teaching kits | $16 | check — test for stripped gears first
MG996R × 2 | Unlikely to be in a drawer; usually issued per-project | $17 | plan to buy

Buy everything

$93worst case, still under ceiling

Typical student

$59servos + supply + filament

Well-stocked lab

$33MG996R + MG90S only

AliExpress route

$42buy-everything, 3 wk wait

The realistic number is $59. Buy the servos, the power supply and filament; source the controller, fasteners, wire, bearings and capacitors from the lab. That lands in the middle of your $50–70 target with the ceiling never in sight, and is unaffected by the ESP32 swap since the controller is lab-sourced in this scenario either way.

14

## Configuration comparison

| A — Ultra-budget | B — Recommended | C — University | D — Stronger
Purchase cost | $48–55 | $55–65 | $17–35 | $85–95
Reach | 275 mm | 315 mm | 315 mm | 315 mm
Payload | 30 g | 55 g | 55 g | 80 g
Base | SG90 | MG90S | lab micro servo | MG90S
Shoulder | MG996R | MG996R | MG996R | DS3218 20 kg·cm
Elbow | MG90S | MG996R | MG996R | MG996R
Gripper | SG90 | MG90S | MG90S | MG90S
Wrist | fixed bracket | SG90 slaved | SG90 slaved | MG90S slaved
Controller | ESP32 | ESP32 | lab ESP32 / Uno / Nano | ESP32
Power | 5 V 3 A charger | 6 V 3 A adapter | bench supply | 6 V 5 A adapter
Shoulder SF | 4.1 | 2.44 | 2.44 | 4.0
Uni components | minimal | minimal | high | optional
Build difficulty | lowest | low | low + sourcing time | low
Use it when | Cash is the binding constraint, or you want a proving build before committing. | Nothing is blocking you. Meets the brief with margin. | The lab genuinely has the parts. Same robot, less money. | B measured short after assembly — not before.

Every column above is the same robot: same CAD files, same assembly, same firmware, same Python. A→B is a 40 mm forearm configuration change and two servo swaps. B→D is one servo and a different mounting plate. You can start at A and arrive at D without reprinting the base, the turret, the upper arm or the gripper.

### How the decision was actually made

Can the cheapest configuration meet the torque requirement?

Yes — but only at 275 mm reach and 30 g payload. An MG90S elbow needs the forearm cut from 120 mm to 80 mm to reach SF 2.08. That satisfies torque by shrinking the robot out of the useful end of the brief's 250–350 mm range. conditional pass

Can university components close the gap at zero cost?

Partly. Controller, power, fasteners, wire, bearings and filament are all plausible lab stock — about $45 of the BOM. MG996R-class servos are not usually sitting in a drawer. Worth asking before ordering; not worth waiting on. partial

Is the step from A to B worth its cost?

Yes, decisively. $8 buys +40 mm reach, +25 g payload and a levelled wrist. There is no cheaper way to buy that much capability on this project. Configuration B selected. selected

Does B leave enough margin, or is D required?

Shoulder SF 2.44, elbow 5.50, base 7.3, gripper 2.7 — every joint clears the SF 2.0 floor. A DS3218 would add $18 to fix a problem that does not exist. Configuration D is not required. Revisit only if measured performance after assembly disagrees with this table. not needed

15
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

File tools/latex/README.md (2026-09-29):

# LaTeX build tool

`tectonic.exe` is [Tectonic](https://tectonic-typesetting.github.io/) v0.17.0, a
self-contained LaTeX engine (MIT/Apache-2.0 licensed, no separate TeX Live/MiKTeX
install needed). It fetches whatever packages a document needs from the TeX Live
CTAN mirror the first time they're used and caches them locally
(`%LOCALAPPDATA%\TectonicProject\Tectonic\cache`), so builds after the first are
fast and mostly offline.

Source: https://github.com/tectonic-typesetting/tectonic/releases/tag/tectonic%400.17.0
(`tectonic-0.17.0-x86_64-pc-windows-msvc.zip`)
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

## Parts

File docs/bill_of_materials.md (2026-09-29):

# Bill of materials

Prices in CAD, estimated from typical Amazon.ca listings. AliExpress runs
roughly 40% cheaper with a ~3-week wait — worth it for the servos if you're
not in a hurry, not worth splitting an order over for everything else.

## BOM A — purchase

| Item | Qty | Cost | Likely in a uni lab? | Note |
|---|---:|---:|---|---|
| MG996R servo | 2 | $17 | Unlikely | Shoulder, elbow. Sold as a 2-pack; a 4-pack at $26 buys spares, and you will want one. |
| MG90S servo | 2 | $13 | Maybe | Base, gripper. |
| SG90 servo | 1 | $3 | Likely | Wrist leveller — lab drawers are usually full of these. |
| 6 V 3 A adapter + barrel jack | 1 | $14 | Likely | A bench supply substitutes entirely for bring-up. |
| ESP32 DevKit (CP2102/CH340) | 1 | $12 | Maybe | Less universal in older teaching labs than a Nano/Uno; a Nano works as a straight fallback (`docs/electronics.md`) at $9 if one's on hand instead. |
| 1000 µF 16 V electrolytic ×2 | 1 | $3 | Very likely | Any parts bin has these. |
| 608ZZ bearing ×2 | 1 | $4 | Likely | From a 10-pack, or a dead skateboard. |
| M3 screw/nyloc assortment | 1 kit | $11 | Very likely | M3×10/12/16/25. Workshop stock. |
| Dupont wire + perfboard | 1 | $8 | Very likely | Lab stock. |
| PLA + PETG filament (~300 g) | — | $8 | Likely | Share of a $25 spool. |
| **Buy absolutely everything** | | **$93** | | Under the $100 ceiling |

**Optional, not in the total above:** a 74HCT125/74AHCT125 level shifter
(~$1) if any servo turns out to jitter on the ESP32's 3.3 V signal — see
`docs/electronics.md`. Most builds won't need it.

## BOM B — university-sourced, with purchased equivalents

| Component | University alternative | Saves | Substitution risk |
|---|---|---:|---|
| Microcontroller | Any ESP32 dev board in the lab, or a Nano/Uno/Mega/Pico (`docs/electronics.md` fallback) | $12 | Low — confirm servo signal quality on whichever board turns up, ESP32 or 5 V AVR |
| Power supply | Bench PSU at 6.0 V / 3 A limit | $14 | None — better than the adapter for testing |
| Fasteners | Workshop M3 stock | $11 | None |
| Wiring, headers, perfboard | Electronics lab stock | $8 | None |
| Bearings | Mechanism-lab 608 or 625 stock | $4 | Low — 625ZZ works with a bore change |
| Filament | Makerspace PLA/PETG | $8 | None |
| Capacitors | Any parts bin | $3 | None |
| Micro servos | SG90/MG90S from teaching kits | $16 | Check — test for stripped gears first |
| **MG996R × 2** | Unlikely to be in a drawer; usually issued per-project | $17 | Plan to buy |
| Ballast stock (mild steel bar/plate, milled to size — `docs/mechanical_design.md` §Ballast) | Metal-shop remnant bin | ~$5–8 | Low — any mild steel blank ≥55 cm³ works, exact stock shape doesn't matter |

## Cost summary

| Scenario | Cost |
|---|---:|
| Buy everything (worst case) | $93 |
| **Typical student (servos + supply + filament, rest sourced)** | **$59** |
| Well-stocked lab (MG996R + MG90S only) | $33 |
| AliExpress route (buy-everything, 3-week wait) | $42 |

**The realistic number is $59** — buy the servos, the power supply and
filament; source the controller, fasteners, wire, bearings and capacitors
from the lab. Lands in the middle of the $50–70 target with the $100 ceiling
never in sight, and is unaffected by the ESP32 swap since the controller is
lab-sourced in this scenario either way. The AliExpress figure moves by only
$1 despite the $3 Amazon.ca delta — ESP32 dev boards are inexpensive there
too, often $5–6, close to what a Nano clone costs.

## Configuration deltas (see `docs/requirements.md` for trigger conditions)

| | A — Ultra-budget | B — Recommended (this BOM) | C — University | D — Stronger |
|---|---:|---:|---:|---:|
| Purchase cost | $48–55 | $55–65 | $17–35 | $85–95 |
| Delta from B | Elbow MG90S instead of MG996R, forearm 80 mm not 120 mm, base/gripper SG90 | — | Swap purchased servos for lab stock where available | Shoulder DS3218 (20 kg·cm) instead of MG996R |

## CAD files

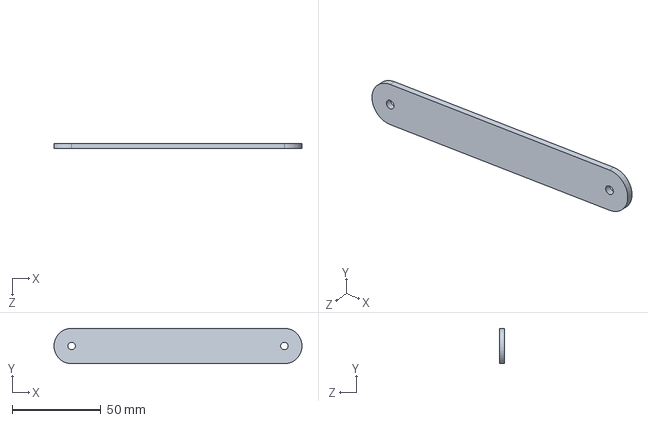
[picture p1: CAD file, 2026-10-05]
cad/parts/upper_arm_plate.SLDPRT
139.9 x 20.0 x 3.00 mm

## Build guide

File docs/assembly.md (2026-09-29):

# Assembly

This is a build-order checklist, not a substitute for the SolidWorks
assembly (`cad/assemblies/`) — follow the drawings for hole positions and
fit; this page is for sequencing, torque/adhesive notes, and the things that
are easy to get wrong in a way that's expensive to undo.

## Before you start

- Print the **tolerance coupon** first (see `docs/mechanical_design.md`)
  and confirm pins seat with light thumb pressure, not a mallet, before
  printing the real parts.
- Dry-fit every part against its mating part before adding hardware.
  Printed parts vary printer-to-printer; catch it now.
- Have the metal servo horns that shipped with each servo on hand — the
  design bolts to them rather than printing splines (see
  `docs/mechanical_design.md`, layer-orientation rule 3).

## Build order

1. **Base and turret**
   - Press the two 608ZZ bearings into the base plate and column.
   - Mount the base servo (MG90S) in its pocket; bolt its metal horn to the
     turret underside — do not glue.
   - Test-rotate the turret by hand through its full range before any other
     part goes on. It should turn freely with no bearing preload.
   - Bolt or press-fit the milled steel ballast block (400 g minimum,
     `docs/mechanical_design.md` §Ballast — see the stability calc in
     `docs/planning_guide.pdf` §6) into the cavity **before** closing the
     snap lid; secured, not loose, so it can't shift during base rotation.
     The robot will tip without it once the arm goes on.

2. **Shoulder**
   - Mount the shoulder servo (MG996R) to the shoulder bracket. Bracket
     should have printed flat per the layer-orientation rules — check the
     layer lines run parallel to the bolt line, not across it.
   - Bolt the bracket to the turret. This joint carries the highest static
     load in the machine (§4.51 kg·cm) — use nyloc nuts here, not plain
     nuts, and don't skip the fillet at the servo cutout if you added one
     after the FEA study.

3. **Upper arm and elbow**
   - Assemble the twin-plate upper-arm link on its spacers.
   - Mount the elbow servo (MG996R) to the elbow bracket, same
     flat-print/bolted-horn rules as the shoulder.
   - Bolt the upper-arm link between the shoulder horn and the elbow
     bracket.

4. **Forearm and wrist**
   - Assemble the twin-plate forearm link.
   - Mount the wrist servo (SG90) at the forearm's far end.
   - Bolt the forearm between the elbow horn and the wrist bracket.

5. **Gripper**
   - Assemble the two mirror-image jaws on their M3 pivot pins, checking the
     gear sectors mesh smoothly through the full open/close range by hand
     before the servo is connected.
   - Mount the MG90S gripper servo and its drive link.
   - Bolt the gripper assembly to the wrist mounting face (the same 24 × 24
     mm interface all three wrist options share — fixed bracket, SG90
     slave, or later a parallelogram linkage).

6. **Electronics**
   - Solder the perfboard: five 3-pin servo headers, barrel jack, 2×1000 µF
     caps, fuse holder, jumper wires to the ESP32's GPIO/GND header pins
     (see `docs/wiring_diagram.svg` for the full pin-out).
   - **Do not connect servos to the ESP32's 5V/VIN pin.** Servo V+ goes to
     the regulated 6 V rail; only GND is shared (`docs/power_system.md`).
   - Route servo signal wires away from the barrel-jack leads.
   - Mount the perfboard and ESP32 to the base plate, near the ballast
     cavity so cable runs to the base/shoulder servos stay short.

7. **Cable routing**
   - Dress the shoulder/elbow/wrist/gripper cables along the arm with cable
     clips (unloaded PLA parts), leaving enough slack at each joint for its
     full range of motion — pull the arm through HOME → full extension →
     folded and check nothing goes taut.

## Bring-up sequence (before Phase 6 kinematics work)

1. Power the perfboard from the **bench supply**, 6.0 V, 3 A current limit,
   ESP32 *not yet* connected to servos.
2. Flash `firmware/arm_firmware/arm_firmware.ino` (Arduino IDE with the
   `esp32` board package and `ESP32Servo` library installed — see
   `docs/electronics.md`), confirm `PING` → `OK ARM v1` over serial with
   servos disconnected.
3. Connect one servo at a time, re-test with a `J`/`G` command each, watching
   for jitter (§Controller in `docs/electronics.md` — add a level shifter on
   that signal line if it doesn't settle) and the bench supply's ammeter. A
   joint drawing current while holding still at a legal angle means a
   binding joint, not an electrical fault — recheck fit before going
   further.
4. Only once all five respond correctly individually, run `HOME` with all
   five connected.

## Calibration

Hobby servos vary — commanding 90° rarely lands exactly on the mechanical
90° you designed for. Per-servo calibration lives in
`software/robot/config.py` as a `(min_us, max_us, angle_offset)` triple per
channel:

1. With the arm mounted and `REL` sent (servos detached, movable by hand),
   position each joint at a known reference angle (e.g. shoulder
   horizontal — use a set square against the upper-arm link).
2. Command that joint via `US <ch> <µs>` starting from the servo's nominal
   center (1500 µs) and adjust until it matches the reference.
3. Record the µs value in `config.py` as that joint's zero offset. Repeat at
   one more angle near the opposite end of travel to get a two-point
   calibration (handles gear-train nonlinearity better than a single
   offset).
4. Re-run `software/robot/kinematics.py`'s self-test, then verify with a
   few `move_to()` calls against a ruler — this is what sets the ±5–8 mm
   repeatability figure in `docs/kinematics.md` as a measured number
   instead of a prediction.

This step is the one most likely to eat a whole evening (see
`docs/testing.md` and the Phase 5 timeline note in the planning guide) —
budget for it rather than being surprised by it.

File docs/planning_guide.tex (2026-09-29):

\documentclass[11pt]{article}

% ---------------------------------------------------------------------
% Packages
% ---------------------------------------------------------------------
\usepackage[a4paper,margin=2.4cm,headheight=14pt]{geometry}
\usepackage{textcomp}
\usepackage{amsmath,amssymb}
\usepackage{booktabs}
\usepackage{array}
\usepackage{longtable}
\usepackage{tabularx}
\usepackage{enumitem}
\usepackage{xcolor}
\usepackage{tikz}
\usetikzlibrary{arrows.meta,positioning}
\usepackage{fancyhdr}
\usepackage{titlesec}
\usepackage{parskip}
\usepackage{caption}
\usepackage{etoolbox}
\usepackage[colorlinks=true,linkcolor=armblue,urlcolor=armblue,citecolor=armblue,linktoc=all]{hyperref}

% ---------------------------------------------------------------------
% Palette + type
% ---------------------------------------------------------------------
\definecolor{armblue}{HTML}{1B44C4}
\definecolor{armgrey}{HTML}{565E70}
\definecolor{armrule}{HTML}{D6DAE3}
\definecolor{armok}{HTML}{166B45}
\definecolor{armwarn}{HTML}{95620A}
\definecolor{armbad}{HTML}{A8332A}

\newcommand{\code}[1]{\texttt{\detokenize{#1}}}
\newcommand{\degsym}{\ifmmode{}^{\circ}\else°\fi}
\newcommand{\micro}{\ifmmode\text{µ}\else µ\fi}
\newcolumntype{L}[1]{>{\raggedright\arraybackslash}p{#1}}
\newcommand{\okmark}{\textcolor{armok}{\textbf{OK}}}
\newcommand{\warnmark}{\textcolor{armwarn}{\textbf{watch}}}
\newcommand{\badmark}{\textcolor{armbad}{\textbf{fails}}}

\titleformat{\section}{\normalfont\Large\bfseries\color{armblue}}{\thesection}{0.6em}{}[{\color{armrule}\titlerule}]
\titleformat{\subsection}{\normalfont\large\bfseries}{\thesubsection}{0.6em}{}
\titlespacing*{\section}{0pt}{1.6em}{0.8em}
\titlespacing*{\subsection}{0pt}{1.2em}{0.5em}

\pagestyle{fancy}
\fancyhf{}
\renewcommand{\headrulewidth}{0.4pt}
\renewcommand{\headrule}{\hbox to\headwidth{\color{armrule}\leaders\hrule height \headrulewidth\hfill}}
\fancyhead[L]{\small\color{armgrey}Desk Arm V1 --- Planning Guide}
\fancyhead[R]{\small\color{armgrey}\leftmark}
\fancyfoot[C]{\small\color{armgrey}\thepage}

\renewcommand{\arraystretch}{1.15}
\setlist[itemize]{topsep=2pt,itemsep=2pt,parsep=0pt}
\setlist[enumerate]{topsep=2pt,itemsep=2pt,parsep=0pt}

\captionsetup{font=small,labelfont={bf,color=armblue},skip=6pt}

% ---------------------------------------------------------------------
\begin{document}

% =======================================================================
% TITLE PAGE
% =======================================================================
\begin{titlepage}
\centering
\vspace*{1.2cm}

{\color{armgrey}\large CAD \$50--70 target \textbullet\ \$100 ceiling \textbullet\ 3D-printed \textbullet\ SolidWorks}\\[1.6cm]

{\Huge\bfseries\color{armblue} Desk Arm}\\[0.3cm]
{\LARGE\bfseries A Low-Cost 3-DOF Desktop Robot Arm}\\[0.6cm]
{\Large V1 Design \& Planning Guide}\\[2.0cm]

\begin{tikzpicture}[scale=0.021, line cap=round, line join=round]
  % table
  \draw[armgrey, line width=1.2] (8,-330) -- (532,-330);
  % base
  \filldraw[fill=armrule!40, draw=armgrey, line width=1] (20,-330) rectangle (200,-316);
  \filldraw[fill=armblue!12, draw=armblue, line width=0.9] (34,-327) rectangle (100,-319);
  \filldraw[fill=armrule!40, draw=armgrey, line width=1] (90,-316) rectangle (130,-258);
  % links
  \draw[armblue!85!black, line width=5.5] (110,-255) -- (187,-163);
  \draw[armblue!85!black, line width=5.0] (187,-163) -- (296,-214);
  \draw[armgrey, line width=3.5] (296,-214) -- (365,-214);
  \draw[armblue, line width=2] (365,-205) -- (379,-199);
  \draw[armblue, line width=2] (365,-223) -- (379,-229);
  % joints
  \filldraw[fill=white, draw=armblue, line width=1.6] (110,-255) circle (3.6);
  \filldraw[fill=white, draw=armblue, line width=1.4] (187,-163) circle (3.2);
  \filldraw[fill=white, draw=armblue, line width=1.2] (296,-214) circle (2.6);
  % reach dimension
  \draw[armblue, line width=0.6, {Latex}-{Latex}] (110,-372) -- (425,-372);
  \node[below, armblue, font=\tiny\sffamily] at (267,-376) {R max = 315 mm};
\end{tikzpicture}

\vspace{1.6cm}
{\large\bfseries Configuration B --- Recommended} \\[0.2cm]
{\color{armgrey} 315~mm reach \textbullet\ 55~g payload \textbullet\ shoulder safety factor 2.44 \textbullet\ \textasciitilde CAD \$59}

\vfill
{\color{armgrey}\small Prepared as the Phase 1 design review and build reference. \\
Engineering numbers verified against \code{calculations/engineering_calcs.py}. \\
\today}

\end{titlepage}

\tableofcontents
\newpage

% =======================================================================
\section{Executive summary}
% =======================================================================

\textbf{Build Configuration B.} Direct-drive revolute arm, equal 120~mm links, 315~mm reach, 55~g design payload. MG996R at the shoulder and elbow, MG90S at the base and gripper, an SG90 slaved as a wrist leveller, ESP32 over USB serial. Worst-case shoulder safety factor is \textbf{2.44}. Purchase cost \textbf{\textasciitilde CAD~\$59} with typical university-lab sourcing (\$93 worst case, buying everything --- still under the \$100 ceiling).

Two things the arithmetic changes about the design, not just describes:

\begin{itemize}
\item \textbf{The base tips over without ballast.} 224~g of moving arm on a 211~mm lever beats a 269~g base on a 90~mm lever (tipping safety factor 0.89). A 400~g ballast cavity in the base plate fixes it (safety factor 2.22) --- see \S\ref{sec:stability}.
\item \textbf{Do not thicken the printed links.} Tip deflection is 0.075~mm against \textasciitilde6~mm of servo backlash --- the structure is already about 80\texttimes\ stiffer than the servos it is bolted to. Added material there costs shoulder margin for no measurable stiffness benefit --- see \S\ref{sec:mechanical}.
\end{itemize}

Configuration A (ultra-budget, 275~mm reach, \$48--55) is viable but saves only \textasciitilde\$8 over B for a materially smaller robot. Configuration D (stronger actuators, \$85--95) is not justified --- every joint in Configuration B already clears the SF~$\geq 2.0$ floor with margin. Full comparison in \S\ref{sec:configs}.

% =======================================================================
\section{Requirements}
\label{sec:req}
% =======================================================================

\subsection{Scope}
V1 is a mechanically and electronically functional 3-DOF arm, controlled manually or programmatically from a PC over USB. No camera, no vision, no AI agent --- that is V2 (\S\ref{sec:v2}), and V1's software is only required not to block it.

\subsection{Degrees of freedom}
\begin{enumerate}
\item \textbf{Base yaw} --- rotates the whole arm about a vertical axis.
\item \textbf{Shoulder} --- raises/lowers the upper arm in the vertical plane the base currently points at.
\item \textbf{Elbow} --- folds the forearm relative to the upper arm, same plane.
\item \textbf{Gripper} (not a positioning DOF) --- opens/closes a two-finger claw.
\item \textbf{Wrist pitch} --- present in hardware (an SG90) but \emph{not} an independently commanded axis. Firmware slaves it to $-(\theta_1+\theta_2)$ so the gripper stays level in every pose (\S\ref{sec:kinematics}).
\end{enumerate}

This is a positioner with 3 controllable spatial DOF $(x,y,z)$ plus grip --- matching the brief exactly, no more.

\subsection{Target dimensions}
\begin{center}
\begin{tabular}{lcc}
\toprule
\textbf{Parameter} & \textbf{Target (brief)} & \textbf{Chosen} \\
\midrule
Base footprint & 150--200~mm & 180~$\times$~180~mm \\
Reach & 250--350~mm & 315~mm kinematic / 290~mm practical \\
Overall height & 250--400~mm & \textasciitilde340~mm (arm vertical, incl.\ gripper) \\
\bottomrule
\end{tabular}
\end{center}

Link lengths: shoulder height $h_0=75$~mm, upper arm $L_1=120$~mm, forearm $L_2=120$~mm, wrist$\to$TCP $L_3=75$~mm. Equal $L_1=L_2$ is deliberate --- see \S\ref{sec:geometry}.

\subsection{Payload and workspace}
\textbf{Design payload: 55~g} at full 315~mm reach --- pens, small tools, USB sticks, small project boxes, small electronics.

\begin{center}
\begin{tabular}{L{2.6cm}L{2.6cm}L{9.6cm}}
\toprule
\textbf{Bound} & \textbf{Value} & \textbf{Set by} \\
\midrule
Outer radius & 315 / 290~mm & Link length / IK conditioning near full extension \\
Inner radius & 130~mm & Forearm-to-turret collision \\
Floor & $z=10$~mm & Jaw-to-table clearance, enforced in firmware \\
Ceiling & $z=315$~mm & Arm vertical \\
Base sweep & $\pm90\degsym$ & No slip ring in V1 \\
\bottomrule
\end{tabular}
\end{center}

Usable desk area: an annular sector, 130--290~mm radius, 180\degsym\ --- about 0.09~m$^2$ directly in front of the base.

\subsection{Budget}
Target personal spend \textbf{CAD \$50--70}; absolute maximum \textbf{CAD \$100}. Configuration B lands at \textbf{\textasciitilde\$59} with typical lab sourcing, \textbf{\textasciitilde\$93} buying everything. Full breakdown in \S\ref{sec:bom}.

\subsection{Decision gate}
Four questions, answered before any implementation started:
\begin{enumerate}
\item \textbf{Configuration B}, built up from A rather than starting at D.
\item \textbf{SG90 slaved wrist: in.} \$3 and 17~g buys a level gripper in every pose.
\item \textbf{University sourcing:} assume lab-available for controller, bench power supply, fasteners, wire, bearings, filament; budget the MG996R pair and MG90S/SG90 as purchased.
\item \textbf{315~mm / 55~g is the right target} --- no known heavier payload requirement.
\end{enumerate}

% =======================================================================
\section{Architecture}
% =======================================================================

Serial revolute arm --- the classic RRR shoulder--elbow chain on a rotating turret. Base yaw is the only vertical axis; shoulder and elbow work in a single vertical plane the base sweeps around. This is the simplest structure that reaches every point on a desk, and the kinematics collapse to one trig problem.

\begin{center}
\small
\begin{tabular}{@{}L{2.1cm}L{2.3cm}L{2.6cm}L{1.5cm}L{5.4cm}@{}}
\toprule
\textbf{Axis} & \textbf{Type} & \textbf{Range} & \textbf{Actuator} & \textbf{Notes} \\
\midrule
1 --- Base yaw & Revolute, vertical & $-90\degsym\ldots+90\degsym$ & MG90S & Turret on 2$\times$608ZZ bearings \\
2 --- Shoulder & Revolute, horiz.\ & $0\degsym\ldots110\degsym$ & MG996R & Highest-loaded joint \\
3 --- Elbow & Revolute, horiz.\ & $-130\degsym\ldots0\degsym$ & MG996R & Elbow-up solution only \\
Wrist (slaved) & Revolute, horiz.\ & $-120\degsym\ldots+30\degsym$ & SG90 & Firmware-computed, not commanded \\
Gripper & Two-finger, meshed & 0--55~mm & MG90S & Compliant tip \\
\bottomrule
\end{tabular}
\end{center}

\subsection{Why a slaved wrist rather than a parallelogram linkage}
A three-DOF positioner has exactly enough freedom to hit an $(x,y,z)$ target and none left over --- gripper pitch is whatever the IK happens to produce, swinging roughly 30\degsym\ across the workspace. Three ways to fix that:

\begin{description}[leftmargin=1.4em,style=nextline]
\item[Twin parallelogram] Two four-bar linkages hold the jaws level with no extra servo, and move the elbow actuator to the turret. Elegant, but six more printed parts and twelve more pivots with slop at every one. \emph{Deferred.}
\item[SG90 slaved wrist --- chosen] One extra micro servo, driven by firmware as a dependent axis. Costs \textasciitilde\$3 and 17~g at 250~mm, which drops shoulder SF from 2.57 to 2.44 --- cheap for level jaws.
\item[Fixed bracket] Bolt the gripper on at a fixed 45\degsym. Zero cost, zero parts, works if objects are always approached from the side. \emph{Configuration A fallback.}
\end{description}

All three bolt to the same 24$\times$24~mm wrist mounting face on the forearm --- start with the fixed bracket, add the SG90 later, try the linkage after that, without touching another part in the assembly.

% =======================================================================
\section{Geometry}
\label{sec:geometry}
% =======================================================================

Equal-length links, $L_1=L_2=120$~mm --- deliberate, not arbitrary: equal lengths make the printed parts nearly identical (one parametric sketch, two configurations), maximise the folded-to-extended reach ratio, and put the workspace's inner boundary where the turret already is. Every dimension traces back to the torque budget in \S\ref{sec:actuators}.

\begin{figure}[h]
\centering
\begin{tikzpicture}[scale=0.024, line cap=round, line join=round, font=\sffamily]
  % table + hatching
  \draw[armgrey, line width=1.3] (8,-330) -- (532,-330);
  \foreach \x in {14,34,...,514} { \draw[armrule, line width=0.7] (\x,-330) -- (\x-8,-338); }
  % base + column
  \filldraw[fill=armrule!35, draw=armgrey, line width=1] (20,-330) rectangle (200,-316);
  \filldraw[fill=armblue!10, draw=armblue, line width=0.9] (34,-327) rectangle (100,-319);
  \node[armblue, font=\tiny] at (67,-345) {ballast cavity};
  \filldraw[fill=armrule!35, draw=armgrey, line width=1] (90,-316) rectangle (130,-258);
  \draw[armrule, line width=0.6, dash pattern=on 3pt off 2pt] (110,-208) -- (110,-372);
  % links
  \draw[black!85, line width=6.5] (110,-255) -- (187,-163);
  \draw[black!85, line width=6.0] (187,-163) -- (296,-214);
  \draw[armgrey, line width=4.0] (296,-214) -- (365,-214);
  \draw[armblue, line width=2.4] (365,-205) -- (379,-199);
  \draw[armblue, line width=2.4] (365,-223) -- (379,-229);
  \filldraw[fill=white, draw=armblue, line width=1.8] (110,-255) circle (4.2);
  \filldraw[fill=white, draw=armblue, line width=1.6] (187,-163) circle (3.6);
  \filldraw[fill=white, draw=armblue, line width=1.4] (296,-214) circle (3.0);
  % labels
  \node[anchor=west, font=\tiny] at (124,-248) {shoulder};
  \node[anchor=west, font=\tiny] at (196,-156) {elbow};
  \node[anchor=south, font=\tiny] at (286,-196) {wrist};
  \node[anchor=west, font=\tiny] at (388,-217) {TCP};
  \node[anchor=west, font=\tiny, armgrey] at (135,-277) {base yaw};
  % dims
  \draw[armgrey, line width=0.5, {Latex}-{Latex}] (52,-255) -- (52,-330);
  \node[anchor=east, font=\tiny, armgrey] at (46,-292) {$h_0{=}75$};
  \node[font=\tiny] at (150,-195) {$L_1{=}120$};
  \node[font=\tiny] at (232,-197) {$L_2{=}120$};
  \node[font=\tiny, armgrey] at (330,-233) {$L_3{=}75$};
  \draw[armblue, line width=0.6, {Latex}-{Latex}] (110,-368) -- (425,-368);
  \node[below, armblue, font=\tiny] at (267,-372) {$R_{max} = 315$~mm};
\end{tikzpicture}
\caption{Side elevation, 1~px~=~1~mm, arm shown mid-stroke. The wrist stays level in every pose, so $L_3$ is a purely horizontal offset in the kinematics.}
\label{fig:elevation}
\end{figure}

\begin{center}
\begin{tabular}{L{3.4cm}L{2.6cm}L{9.0cm}}
\toprule
\textbf{Parameter} & \textbf{Value} & \textbf{Rationale} \\
\midrule
Shoulder height $h_0$ & 75~mm & Elbow folds without hitting the turret \\
Upper arm $L_1$ & 120~mm & Torque-driven --- 140~mm drops shoulder SF below 2.1 \\
Forearm $L_2$ & 120~mm & Equal to $L_1$ --- same printed profile \\
Wrist$\to$TCP $L_3$ & 75~mm & Jaw depth + clearance for a 30~mm object \\
Max TCP reach & 315~mm & Within the 250--350~mm brief \\
Base footprint & 180$\times$180~mm & Drives the tipping calculation, \S\ref{sec:stability} \\
Jaw opening & 0--55~mm & Pen through small project box \\
\bottomrule
\end{tabular}
\end{center}

% =======================================================================
\section{Actuator selection}
\label{sec:actuators}
% =======================================================================

\subsection{Method}
Static gravity-holding torque at the worst-case pose (fully extended, horizontal --- also the normal working pose for a desk arm reaching across the table). Dynamic terms are small at the speeds this arm moves at (under 10\% of the gravity term at the firmware's 60\degsym/s slew limit) and are absorbed by the safety-factor floor rather than modelled explicitly. Target safety factor: \textbf{$\geq 2.0$}, evaluated at 6.0~V rated torque --- roughly the point below which a hobby servo holding a static pose runs hot instead of idling near stall current.

\subsection{Mass budget}
Horizontal distance from the shoulder axis, arm fully extended --- the worst case for every load in the chain. Verified by \code{calculations/engineering_calcs.py}.

\begin{center}
\begin{tabular}{lrrr}
\toprule
\textbf{Item} & \textbf{Mass} & \textbf{Distance} & \textbf{Moment} \\
\midrule
Upper-arm link pair + spacers & 30~g & 60~mm & 1{,}800~g\textperiodcentered mm \\
Elbow servo (MG996R) + bracket & 65~g & 120~mm & 7{,}800~g\textperiodcentered mm \\
Forearm link pair + spacers & 25~g & 180~mm & 4{,}500~g\textperiodcentered mm \\
Wrist servo (SG90) + bracket & 17~g & 250~mm & 4{,}250~g\textperiodcentered mm \\
Gripper assembly (MG90S + jaws) & 32~g & 285~mm & 9{,}120~g\textperiodcentered mm \\
Design payload & 55~g & 320~mm & 17{,}600~g\textperiodcentered mm \\
\midrule
\textbf{Moving assembly total} & \textbf{224~g} & CoM 201~mm & \textbf{45{,}070~g\textperiodcentered mm} \\
\bottomrule
\end{tabular}
\end{center}

Below the shoulder (drives base stability, not shoulder torque): base plate 100~g, column + turret 60~g, base servo 14~g, shoulder servo 55~g, hardware 40~g $\to$ \textbf{269~g}.

The elbow servo alone is 29\% of the moving mass, sitting at the point in the chain where moving it costs the most shoulder torque --- the highest-leverage future change, if shoulder margin ever becomes a problem, is relocating it to the turret behind a linkage (\textasciitilde1.4~kg\textperiodcentered cm), not implemented in V1.

\subsection{Torque calculations}
\begin{align*}
\text{Shoulder: } \tau_1 &= g\sum_i m_i d_i = 9.81 \times 0.04507~\text{kg\,m} = 0.442~\text{N\,m} = 4.51~\text{kg\textperiodcentered cm} \\[4pt]
\text{Elbow: } \tau_2 &= 9.81\times(0.025{\times}0.060 + 0.017{\times}0.130 + 0.032{\times}0.165 + 0.055{\times}0.200) \\
&= 9.81 \times 0.01999 = 0.196~\text{N\,m} = 2.00~\text{kg\textperiodcentered cm} \\[4pt]
\text{Base yaw: } \tau_0 &\approx I\alpha + \text{drag} = 0.0056\times3.5 + \text{drag} \approx 0.30~\text{kg\textperiodcentered cm} \\[4pt]
\text{Wrist: } \tau_3 &= g\left[0.032(0.285{-}0.240) + 0.055(0.320{-}0.240)\right] = 0.057~\text{N\,m} = 0.58~\text{kg\textperiodcentered cm}
\end{align*}

\subsection{Servo table}
\begin{center}
\begin{tabular}{lllrrrl}
\toprule
\textbf{Joint} & \textbf{Servo} & & \textbf{Req.} & \textbf{Target $\times2$} & \textbf{Rated @6V} & \textbf{SF} \\
\midrule
Base & MG90S & & 0.30 & 0.60 & 2.20 & 7.34 \okmark \\
\textbf{Shoulder} & \textbf{MG996R} & \emph{(sizing joint)} & \textbf{4.51} & \textbf{9.02} & \textbf{11.00} & \textbf{2.44} \okmark \\
Elbow & MG996R & & 2.00 & 4.00 & 11.00 & 5.50 \okmark \\
Wrist (slave) & SG90 & & 0.58 & 1.17 & 1.80 & 3.08 \okmark \\
Gripper & MG90S & & 0.82 & 1.64 & 2.20 & 2.70 \okmark \\
\bottomrule
\end{tabular}
\end{center}
\emph{All kg\textperiodcentered cm. On a 5~V supply the MG996R drops to \textasciitilde9.4~kg\textperiodcentered cm and shoulder SF falls to 2.08 --- still acceptable, which is why a 5~V/3~A phone charger is a legitimate power fallback (\S\ref{sec:power}).}

\textbf{Why the elbow is over-specified (SF~5.50), deliberately:} it needs 2.00~kg\textperiodcentered cm, so at SF~2 it needs 4.0. The MG90S tops out at 2.2 and fails. The next rung up, an MG92B at 3.5~kg\textperiodcentered cm (\textasciitilde\$8), still gives only SF~1.75 --- and costs more than an MG996R. The MG996R wins by default and the margin is free.

\subsection{Gripper: SG90 vs MG90S}
Required clamp force for a 55~g object, $\mu=0.5$ (rubber pad, conservative): $mg/2\mu = 0.54$~N. Design target: \textbf{4~N per jaw} --- about 7$\times$ the physics minimum, because real grips are off-centre and objects get bumped.

\begin{align*}
\text{Jaw pivot torque} &= 4.0~\text{N} \times 0.030~\text{m} = 0.12~\text{N\,m} \\
\text{Servo torque (1.5:1 reduction)} &= 0.12 / 1.5 = 0.080~\text{N\,m} = 0.82~\text{kg\textperiodcentered cm}
\end{align*}

\begin{center}
\begin{tabular}{L{2.2cm}L{6.4cm}L{6.4cm}}
\toprule
 & \textbf{SG90} & \textbf{MG90S (chosen)} \\
\midrule
Mass / cost & 9~g / \textasciitilde\$2 & 13.4~g / \textasciitilde\$6 \\
Gears & Nylon --- strips on a hard stall & Metal --- survives stalls/knocks \\
Footprint & 22.8$\times$12.2$\times$22.5~mm, 32~mm span & \textbf{Identical} --- drop-in either way \\
\bottomrule
\end{tabular}
\end{center}

Both pass on torque. The decision is about what happens the twentieth time the gripper closes on something it cannot close on --- metal gears survive it, nylon eventually strips. The identical footprint means the mount is one printed part regardless of which servo goes in it.

\textbf{Mechanism:} two mirror-image printed jaws on M3 pins with meshed gear sectors (module 1.5, \textasciitilde10 teeth engaged) --- one servo drives one jaw, the sectors force the other to mirror it. Self-centring, cannot desync. Jaw faces carry a 90\degsym\ V-groove plus a rubber pad. \textbf{Compliance matters more than gear material:} thin the last 12~mm of each jaw to 1.6~mm so it flexes \textasciitilde1~mm under load --- one commanded ``closed'' angle then grips a range of object sizes without ever driving the servo into a hard stall.

% =======================================================================
\section{Base stability}
\label{sec:stability}
% =======================================================================

Tipping about the front edge of the base plate, arm fully extended, payload at maximum reach. The shoulder axis sits 10~mm forward of the base axis, so the moving CoM is 211~mm out.

\begin{align*}
M_{\text{over}} &= 0.224 \times 9.81 \times (0.211 - 0.090) = 0.266~\text{N\,m} \\[4pt]
M_{\text{rest, no ballast}} &= 0.269 \times 9.81 \times 0.090 = 0.238~\text{N\,m} \quad\Rightarrow\quad \text{SF} = 0.89 \quad \badmark \\[4pt]
M_{\text{rest, +400 g ballast}} &= 0.669 \times 9.81 \times 0.090 = 0.591~\text{N\,m} \quad\Rightarrow\quad \text{SF} = 2.22 \quad \okmark
\end{align*}

\textbf{The arm as drawn tips over.} 224~g on a 211~mm lever beats a 269~g base on a 90~mm lever, and no amount of careful printing fixes that --- it is easy to miss on paper because the whole robot only weighs \textasciitilde500~g.

\subsection{Fixes}
\begin{description}[leftmargin=1.4em,style=nextline]
\item[Ballast the base --- primary] Seal a 66$\times$66$\times$18~mm cavity into the base plate with a snap lid. Fill with washers, sand, or spare screws. \textbf{400~g minimum, 500~g preferred.} Costs nothing and lowers the CoM as well as raising the mass.
\item[Park the supply on the plate] A 6~V~3~A brick weighs 150--250~g. Recessed behind the column, it becomes free ballast plus shorter power leads.
\item[Clamp it down --- optional] Two 8~mm slots at the rear take a small C-clamp. Makes tipping structurally impossible, worth having for fast moves, but should not be the only thing keeping the arm upright.
\end{description}

\textbf{Dynamic loading is worse than this static calculation.} Decelerating the arm at the end of a fast reach adds an inertial term this analysis ignores --- the target is SF~2.2, not 1.2, and firmware slew-limits every joint to 60\degsym/s for exactly this reason.

% =======================================================================
\section{Kinematics}
\label{sec:kinematics}
% =======================================================================

No DH tables, no Jacobians, no numerical solver. Base rotation decouples completely from shoulder/elbow, leaving a two-link planar problem with a closed-form solution --- implemented in \code{software/robot/kinematics.py} (\textasciitilde40 lines including workspace checks, with a self-test that reproduces every number in this section).

\subsection{Forward kinematics}
\begin{align*}
r &= L_1\cos\theta_1 + L_2\cos(\theta_1{+}\theta_2) + L_3 \\
z &= h_0 + L_1\sin\theta_1 + L_2\sin(\theta_1{+}\theta_2) \\
x &= r\cos\theta_0 \qquad y = r\sin\theta_0
\end{align*}
$L_3$ adds directly to $r$ with no trig term --- the payoff of the levelled wrist. Without it, $L_3$ would carry a $\cos(\theta_1{+}\theta_2{+}\theta_3)$ factor and the inverse problem stops being closed-form.

\subsection{Inverse kinematics}
\begin{align*}
\theta_0 &= \operatorname{atan2}(y, x) \\[2pt]
r' &= \sqrt{x^2+y^2} - L_3 \qquad z' = z - h_0 \\[2pt]
D &= \frac{r'^2 + z'^2 - L_1^2 - L_2^2}{2 L_1 L_2} \qquad \text{(unreachable if } |D| > 1\text{, checked before acos)} \\[2pt]
\theta_2 &= -\arccos(D) \qquad \text{(negative root = elbow-up)} \\[2pt]
\theta_1 &= \operatorname{atan2}(z', r') - \operatorname{atan2}\!\big(L_2\sin\theta_2,\ L_1+L_2\cos\theta_2\big) \\[2pt]
\theta_3 &= -(\theta_1+\theta_2) \qquad \text{(slaved wrist, jaws level)}
\end{align*}

The two $\arccos$ roots are elbow-up and elbow-down. Elbow-down puts the elbow below the table on nearly every desk-height target, so the solver takes the negative root unconditionally.

\subsection{Validation order, before anything moves}
\begin{enumerate}
\item \textbf{Reachability} --- $|D|\leq 1$ and $130 \leq \sqrt{x^2+y^2} \leq 290$~mm.
\item \textbf{Joint limits} --- every $\theta$ inside its mechanical range (\S3.2).
\item \textbf{Table clearance} --- $z \geq 10$~mm, and the elbow itself above the table.
\item \textbf{Path check} --- for a Cartesian move, interpolate 20 waypoints and validate each; a straight line between two legal poses can pass through an illegal one.
\end{enumerate}

\textbf{The accuracy limit is backlash, not mathematics.} An MG996R has 1--2\degsym\ of gear lash plus potentiometer deadband. At the 240~mm shoulder+elbow lever, 1.5\degsym\ is \textbf{6~mm at the gripper}. Expect \textbf{$\pm$5--8~mm} repeatability and design around it: approach every target from the same direction, and let the 55~mm jaw opening absorb the rest. No amount of IK precision buys back a millimetre of this.

% =======================================================================
\section{Electronics}
\label{sec:elec}
% =======================================================================

\begin{center}
\begin{tikzpicture}[font=\small, node distance=1.4cm, >=Latex]
  \node[draw, rounded corners, minimum width=2.6cm, minimum height=0.9cm] (pc) {PC};
  \node[draw, rounded corners, minimum width=3.4cm, minimum height=0.9cm, right=2.2cm of pc] (nano) {ESP32};
  \node[draw, rounded corners, minimum width=3.2cm, minimum height=0.9cm, right=2.2cm of nano] (servos) {5 $\times$ servo};
  \node[draw, rounded corners, minimum width=3.6cm, minimum height=0.9cm, below=1.3cm of nano] (psu) {6~V 3~A supply};
  \draw[->] (pc) -- node[above,font=\scriptsize]{USB} (nano);
  \draw[->] (nano) -- node[above,font=\scriptsize]{PWM $\times$5} (servos);
  \draw[->] (psu) -| node[above,font=\scriptsize,pos=0.75]{V+ rail} (servos);
  \draw[-] (psu) -- node[left,font=\scriptsize]{GND (common)} (nano);
\end{tikzpicture}
\end{center}

\subsection{Controller: ESP32 (DevKitC or equivalent)}
Full pin-out, colour-coded nets and the grounding/power checklist below are also drawn out as a standalone diagram, \code{wiring_diagram.svg}, alongside this guide. Revised from an original Arduino Nano choice. The Nano's advantage was native \textbf{5~V logic} --- hobby servos want a 5~V pulse, and a 3.3~V board introduces a question with no clean answer on paper: some servos latch reliably on 3.3~V, some jitter, and the difference only shows up after assembly. In practice, the SG90/MG90S/MG996R family used here decodes PWM through an analog RC input stage that a 3.3~V high clears --- a well-worn combination, not a gamble. \textbf{Test each servo before final assembly}; the documented fallback for a unit that jitters is a 74HCT125/74AHCT125 quad buffer (\textasciitilde\$1, covers all five signal lines), not a controller change. In exchange for accepting that one check: a dual-core chip with far more flash/RAM/GPIO than this project needs, a similar street price to the Nano, and Wi-Fi/BT already on board if a future V2 ever wants the arm untethered (unused, not required, by \code{docs/v2_ai_roadmap.md}). Requires the \code{ESP32Servo} library in place of the stock \code{Servo.h} (the ESP32 Arduino core ships neither) --- the \code{attach()}/\code{writeMicroseconds()} API is unchanged, it just rides the chip's LEDC PWM peripheral instead of a hardware timer.

\textbf{Deliberately not included:} a PCA9685 driver board (five servos fit on five ESP32 GPIOs already --- the board solves a problem that starts around twelve servos); encoders or current sensing (hobby servos have no position-feedback path to expose); limit switches (servos are absolute-position devices and already know where they are at power-on).

\textbf{Fallback:} an Arduino Nano/Uno remains a straightforward substitute if an ESP32 isn't available, or a servo won't settle at 3.3~V even behind a level shifter --- same pin roles, same serial protocol, swap \code{ESP32Servo} back for stock \code{Servo.h} and drop the timer-allocation calls in \code{setup()}.

\subsection{Serial protocol}
ASCII, line-oriented, one command per line, every command answered.

\begin{center}
\begin{tabular}{L{4.2cm}L{4.0cm}L{6.8cm}}
\toprule
\textbf{Command} & \textbf{Reply} & \textbf{Purpose} \\
\midrule
\code{PING} & \code{OK ARM v1} & Port identification and liveness \\
\code{J <base> <sh> <el>} & \code{OK} / \code{ERR LIMIT <joint>} & Absolute joint angles, degrees \\
\code{G <0-100>} & \code{OK} & Gripper, 0 closed, 100 open \\
\code{US <ch> <us>} & \code{OK} / \code{ERR RANGE} & Raw pulse, \code{ch}=B/S/E/W/G, calibration only \\
\code{HOME} & \code{OK} & Slew to the safe folded pose \\
\code{STOP} & \code{OK} & Freeze at the current position \\
\code{REL} & \code{OK} & Detach all servos \\
\code{STAT} & angles + \code{us} & Current commanded state \\
\bottomrule
\end{tabular}
\end{center}

The split is deliberate: \textbf{the firmware owns safety, the PC owns intelligence.} Joint limits and slew limiting live on the ESP32 and cannot be bypassed by a buggy Python script --- or, later, a confused AI agent.

% =======================================================================
\section{Power system}
\label{sec:power}
% =======================================================================

\begin{center}
\begin{tabular}{lrrrr}
\toprule
\textbf{Servo} & \textbf{Qty} & \textbf{Idle} & \textbf{Moving} & \textbf{Stall} \\
\midrule
MG996R & 2 & 0.17~A & 0.6--0.9~A & 2.5~A \\
MG90S & 2 & 0.08~A & 0.2--0.4~A & 0.7~A \\
SG90 & 1 & 0.06~A & 0.2~A & 0.65~A \\
\midrule
\textbf{Rail total} & 5 & \textbf{0.56~A} & \textbf{1.2--1.8~A} & \textbf{7.05~A} \\
\bottomrule
\end{tabular}
\end{center}

The 7.05~A all-stall figure is not a design case --- it requires every joint jammed simultaneously. The design case is \textbf{1.8~A continuous, \textasciitilde3.5~A transient} at direction reversals.

\textbf{Specification: 6.0~V, 3~A regulated (18~W), barrel jack, 3~A fuse.} 6.0~V because MG996R torque is quoted at 6~V; at 5~V shoulder SF falls from 2.44 to 2.08. Bulk capacitance: 2$\times$1000~\micro F at the servo headers. $C\Delta V/I = 2000~\micro\text{F}\times0.5\text{V}/2\text{A} = 0.5$~ms --- enough to kill a switching spike, \emph{not} a substitute for a supply that can source the current.

\textbf{Rejected: 4$\times$AA batteries.} Nominal voltage is fine --- 4 fresh alkaline cells land around 6.4~V, inside the 4.8--6.6~V window --- but internal resistance is not: alkaline AAs run \textasciitilde0.15--0.3~$\Omega$ each, so \textasciitilde0.6--1.2~$\Omega$ for the pack. At the 1.8~A design-case draw that is 1.1--2.2~V of sag before the 3.5~A transient case makes it worse --- the same failure mode as the capacitor note above, a source that cannot hold voltage under real load. NiMH cells have lower internal resistance and are the better chemistry if a battery pack is ever used for real, but even then treat it as good for a single-joint bench check, not for running the assembled arm.

\textbf{Three rules, each of which has ended someone's project:} never feed the servo rail from the ESP32's 5V/VIN pin or USB (that pin sits upstream of the board's own 3.3~V logic regulator and reflects whatever the USB port can source, typically \textasciitilde500~mA; five servos will brown it out mid-move); servo ground and ESP32 ground must be joined, or the PWM has no reference and servos twitch randomly; no 7.4~V LiPo direct to the rail --- it will destroy the MG90S and SG90 within minutes.

% =======================================================================
\section{Software architecture}
% =======================================================================

\begin{center}
\begin{tabular}{L{5.6cm}L{9.4cm}}
\toprule
\textbf{Layer} & \textbf{Owns} \\
\midrule
\code{firmware/arm_firmware/} (Arduino C++) & Joint limits, slew rate --- \emph{safety} \\
\code{software/robot/} (Python) & Kinematics, trajectory, transport, the \code{Arm} API \\
\code{software/cli.py}, \code{sequences.py} & Manual control and demo/test routines \\
\emph{V2 (not built)} & \code{software/vision/}, \code{software/agent/} --- add here only \\
\bottomrule
\end{tabular}
\end{center}

The public surface everything else is meant to use --- the CLI, the demo sequences, and eventually the V2 agent --- is \code{robot.arm.Arm}:

\begin{quote}\ttfamily\small
arm.home()\\
arm.move\_joints(base, shoulder, elbow)\\
arm.move\_to(x, y, z)\quad\rmfamily\itshape\small (Cartesian, validated, interpolated)\\
\ttfamily arm.grip(percent)\\
arm.pickup(x, y, z)\\
arm.place(x, y, z)
\end{quote}

This is the V1$\to$V2 contract (\S\ref{sec:v2}): in V2 the agent does not get its own motion code, its own limits, or its own IK --- it calls exactly these six methods. No ROS, no behaviour trees, no message bus --- a 300~mm desk arm with five servos does not have a software problem that a Python class cannot solve.

% =======================================================================
\section{Mechanical design and printing}
\label{sec:mechanical}
% =======================================================================

Links are twin printed side plates on printed spacers --- a box section that is stiff in bending, prints flat with no supports, and puts every bolt in double shear. Roughly 14 unique parts, 20 printed pieces, \textasciitilde300~g of filament, 18--22~h print time.

\subsection{Material assignment}
\begin{center}
\begin{tabular}{L{3.8cm}L{1.6cm}L{9.6cm}}
\toprule
\textbf{Part} & \textbf{Material} & \textbf{Why} \\
\midrule
Base, column, turret & PLA & Stiffness and flatness; not impact-loaded \\
Upper arm, forearm links & PLA & $E\approx3.5$~GPa vs.\ PETG's 2.0 --- deflection matters most \\
Shoulder / elbow brackets & PETG & Highest bending stress; layer adhesion matters most \\
Servo horn adapters & PETG & Small, bolted, loaded to peel layers apart \\
Gripper jaws & PETG & Designed to flex; PLA would snap at the flex section \\
Spacers, clips, tray & PLA & Unloaded \\
Ballast block & Mild steel, milled & Not printed --- see below \\
\bottomrule
\end{tabular}
\end{center}
Print settings: 0.4~mm nozzle, 0.2~mm layers, \textbf{4 perimeters}, 30\% gyroid, 5 top/bottom --- perimeter count dominates strength in a thin printed part.

\subsection{Ballast}
A solid milled block, not loose fill --- a fixed, known mass at a fixed position matches the stability calc's assumption exactly and cannot shift the CoM as the base rotates. \textbf{Mild steel, \textasciitilde50--55~cm\textsuperscript{3} for the 400~g target} ($\rho\approx7.85$~g/cm\textsuperscript{3}): a 60$\times$60$\times$15~mm block is \textasciitilde424~g, clearing the minimum with margin. Steel over aluminium specifically for the footprint --- aluminium ($\rho\approx2.70$) needs \textasciitilde3$\times$ the volume for the same mass, and the ballast cavity already competes for space with the column and base-servo mount inside the 180$\times$180~mm base. Weigh the actual cut block and trim (or size up the blank) to clear 400~g --- mild steel density varies enough between alloys (7.75--7.87~g/cm\textsuperscript{3}) that this is measure-don't-assume, same as everything else safety-factor-adjacent in this guide. Bolt or press-fit it into the cavity; a block free to slide during base rotation turns a designed-in stability margin into an unmeasured one.

\subsection{Layer orientation --- three rules that decide whether this works}
\begin{enumerate}
\item \textbf{Print brackets flat, never standing up.} Loaded perpendicular to the layer planes, a printed part manages only \textasciitilde40--60\% of its in-plane strength.
\item \textbf{Every bolt hole axis is normal to the build plate.} Bolts then clamp \emph{across} layers in compression, not trying to split them apart.
\item \textbf{Never print a servo spline.} A printed 25-tooth spline \emph{will} round off. Bolt the metal horn that shipped with the servo to the printed part with 2--3~M2 screws --- the single most common failure mode in printed arms, designed out from part one.
\end{enumerate}

\subsection{Where FEA earns its time}
\textbf{Worth running (2 studies):} the shoulder bracket (0.44~N\,m through a bolted interface, stress concentration at the servo cutout --- the one part where intuition is unreliable); the upper-arm link's elbow-servo pocket (expect the answer to be ``add a 3~mm fillet''). \textbf{Not worth running:} everything else --- the hand calculation below already answers the question.

\begin{align*}
I &= 2\times\frac{3\times20^3}{12} = 4000~\text{mm}^4 \\
\delta &= \frac{FL^3}{3EI} = \frac{1.3 \times 120^3}{3\times2500\times4000} = 0.075~\text{mm}
\end{align*}

\textbf{Seventy-five microns.} The structure is \textasciitilde80$\times$ stiffer than the servo backlash it is bolted to (\S\ref{sec:kinematics}). \textbf{Do not thicken these links} --- every gram added buys nothing measurable and costs shoulder safety factor directly.

\subsection{Parametric strategy}
One global variables file drives $L_1$, $L_2$, $L_3$, $h_0$, plate thickness and pin diameter across every part. A servo-pocket library feature with a two-row design table (standard: MG996R-class, 40.7$\times$19.7$\times$42.9~mm; micro: MG90S/SG90-class, 22.8$\times$12.2$\times$22.5~mm) means swapping servo sizes is a configuration change, not a redesign --- this is what makes Configurations A--D one robot instead of four. 0.2~mm nominal clearance on every pin and pocket, tuned once via a printed tolerance coupon. Full part list and file layout in \code{cad/README.md}.

% =======================================================================
\section{Bill of materials}
\label{sec:bom}
% =======================================================================

\subsection{BOM A --- purchase}
\begin{center}
\small
\begin{tabular}{L{6.4cm}rrL{4.4cm}}
\toprule
\textbf{Item} & \textbf{Qty} & \textbf{Cost} & \textbf{Likely in a lab?} \\
\midrule
MG996R servo & 2 & \$17 & Unlikely \\
MG90S servo & 2 & \$13 & Maybe \\
SG90 servo & 1 & \$3 & Likely \\
6~V 3~A adapter + barrel jack & 1 & \$14 & Likely (bench PSU substitutes) \\
ESP32 DevKit (CP2102/CH340) & 1 & \$12 & Maybe --- a Nano works as a \$9 fallback \\
1000~\micro F 16~V electrolytic $\times$2 & 1 & \$3 & Very likely \\
608ZZ bearing $\times$2 & 1 & \$4 & Likely \\
M3 screw/nyloc assortment & 1 kit & \$11 & Very likely \\
Dupont wire + perfboard & 1 & \$8 & Very likely \\
PLA + PETG filament (\textasciitilde300~g) & --- & \$8 & Likely \\
\midrule
\textbf{Buy absolutely everything} & & \textbf{\$93} & \emph{under the \$100 ceiling} \\
\bottomrule
\end{tabular}
\end{center}

\emph{Optional, not in the total above:} a 74HCT125/74AHCT125 level shifter (\textasciitilde\$1) if a servo jitters on the ESP32's 3.3~V signal (\S\ref{sec:power}) --- most builds won't need it.

\subsection{BOM B --- university-sourced}
\begin{center}
\small
\begin{tabular}{L{7.2cm}rL{5.4cm}}
\toprule
\textbf{Component} & \textbf{Saves} & \textbf{Substitution risk} \\
\midrule
Microcontroller (ESP32, or Uno/Nano/Mega/Pico fallback) & \$12 & Low --- confirm servo signal quality \\
Power supply (bench PSU) & \$14 & None --- better for testing \\
Fasteners (workshop M3 stock) & \$11 & None \\
Wiring, headers, perfboard & \$8 & None \\
Bearings (mechanism-lab stock) & \$4 & Low \\
Filament (makerspace stock) & \$8 & None \\
Capacitors & \$3 & None \\
Micro servos (teaching kits) & \$16 & Check for stripped gears first \\
\textbf{MG996R $\times$2} & \$17 & \textbf{Plan to buy} --- unlikely on the shelf \\
Ballast stock (mild steel remnant, milled to size, \S\ref{sec:mechanical}) & \$5--8 & Low --- any mild steel blank $\geq$55~cm\textsuperscript{3} works \\
\bottomrule
\end{tabular}
\end{center}

\subsection{Cost summary}
\begin{center}
\begin{tabular}{lr}
\toprule
\textbf{Scenario} & \textbf{Cost} \\
\midrule
Buy everything (worst case) & \$93 \\
\textbf{Typical student (servos + supply + filament, rest sourced)} & \textbf{\$59} \\
Well-stocked lab (MG996R + MG90S only) & \$33 \\
AliExpress route (buy-everything, 3-week wait) & \$42 \\
\bottomrule
\end{tabular}
\end{center}

The \$59 typical-student figure is unaffected by the ESP32 swap --- the controller is lab-sourced in that scenario either way. The AliExpress total moves by only \$1 despite the \$3 Amazon.ca delta, since ESP32 dev boards are inexpensive there too, often \$5--6.

% =======================================================================
\section{Configuration comparison}
\label{sec:configs}
% =======================================================================

\begin{center}
\small
\setlength{\tabcolsep}{3.5pt}
\begin{tabular}{L{2.2cm}L{2.9cm}L{2.9cm}L{2.9cm}L{2.9cm}}
\toprule
 & \textbf{A --- Ultra-budget} & \textbf{B --- Recommended} & \textbf{C --- University} & \textbf{D --- Stronger} \\
\midrule
Purchase cost & \$48--55 & \$55--65 & \$17--35 & \$85--95 \\
Reach & 275~mm & 315~mm & 315~mm & 315~mm \\
Payload & 30~g & 55~g & 55~g & 80~g \\
Base & SG90 & MG90S & lab micro servo & MG90S \\
Shoulder & MG996R & MG996R & MG996R & DS3218 (20~kg\textperiodcentered cm) \\
Elbow & MG90S & MG996R & MG996R & MG996R \\
Gripper & SG90 & MG90S & MG90S & MG90S \\
Wrist & fixed bracket & SG90 slaved & SG90 slaved & MG90S slaved \\
Shoulder SF & 4.1 & 2.44 & 2.44 & 4.0 \\
University components & minimal & minimal & \textbf{high} & optional \\
\bottomrule
\end{tabular}
\end{center}

Every column is the \emph{same robot}: same CAD files, same assembly, same firmware, same Python. A$\to$B is a 40~mm forearm configuration change and two servo swaps. B$\to$D is one servo and a different mounting plate.

\subsection{Decision trail}
\begin{description}[leftmargin=1.4em,style=nextline]
\item[G1 --- Can the cheapest configuration meet torque requirements?] Yes, but only at 275~mm reach and 30~g payload --- satisfies torque by shrinking the robot to the low end of the brief's range. \emph{Conditional pass.}
\item[G2 --- Can university components close the gap at zero cost?] Partly --- \textasciitilde\$45 of the BOM is plausible lab stock, but MG996R-class servos usually are not. \emph{Partial.}
\item[G3 --- Is the step from A to B worth its cost?] Yes, decisively: \$8 buys +40~mm reach, +25~g payload, and a levelled wrist. \textbf{Configuration B selected.}
\item[G4 --- Does B leave enough margin, or is D required?] Every joint clears SF~2.0. A DS3218 would add \$18 to fix a problem that does not exist. \textbf{Configuration D not required.}
\end{description}

% =======================================================================
\section{Component fallbacks}
% =======================================================================

\begin{center}
\small
\begin{tabular}{L{2.1cm}L{2.6cm}L{3.5cm}L{2.6cm}L{3.5cm}}
\toprule
\textbf{Component} & \textbf{Primary} & \textbf{If unavailable} & \textbf{If too weak} & \textbf{University} \\
\midrule
Shoulder & MG996R & MG995 & DS3218 & Any 9--20~kg\textperiodcentered cm servo \\
Elbow & MG996R & MG90S + $L_2{=}80$mm & 2nd MG996R & Standard-frame servo \\
Base & MG90S & SG90 & MG996R & Any micro servo \\
Gripper & MG90S & SG90 + lighter jaws & MG92B & Check for stripped gears \\
Wrist & SG90 & fixed 45\degsym\ bracket & MG90S & Any micro servo \\
Controller & ESP32 & Nano/Uno (5V) & --- & ESP32/Uno/Nano/Pico \\
Power & 6V 3A adapter & 5V 3A charger ($-$15\%) & 6V 5A adapter & Bench supply \\
\bottomrule
\end{tabular}
\end{center}

\subsection{Geometry fallback --- apply strictly in this order}
\begin{enumerate}
\item \textbf{Cut the payload} --- 55~g$\to$30~g removes 39\% of the shoulder moment for free.
\item \textbf{Shorten the forearm} --- $L_2$ 120$\to$80~mm, reach falls to 275~mm.
\item \textbf{Lighten the prints} --- 3~mm$\to$2.5~mm plates, 30\%$\to$20\% infill; \textasciitilde12~g saved, deflection stays under 0.15~mm.
\item \textbf{Only then, a bigger servo} --- and re-check steps 1--3 first.
\end{enumerate}

A 350~mm arm at 55~g needs \textasciitilde5.4~kg\textperiodcentered cm at the shoulder --- an MG996R right at the edge, or \$18 more for a DS3218. The 315~mm arm clears 4.51 comfortably on the \$8 servo. 35~mm of reach is not worth doubling the actuator budget.

% =======================================================================
\section{Design risks}
% =======================================================================

\begin{center}
\small
\begin{tabular}{@{}p{4.6cm}lp{7.6cm}@{}}
\toprule
\textbf{Risk} & \textbf{Severity} & \textbf{Mitigation} \\
\midrule
Printed servo-horn interface strips & \badmark & Never print splines --- bolt the metal horn on. Designed in from part one. \\
Base tips forward & \badmark & 400~g ballast cavity + supply on the plate (\S\ref{sec:stability}). Verify by hand before power-on. \\
Brownout resets mid-move & \badmark & Separate 3~A servo rail, common ground, 2$\times$1000~\micro F, never the ESP32's 5V/VIN pin. \\
Servo jitters on ESP32's 3.3~V signal & \warnmark & Test each servo before final assembly; add a 74HCT125 level shifter (\textasciitilde\$1) on that signal line, or fall back to a Nano (\S\ref{sec:bom}) --- see \S Controller in Electronics. \\
Backlash limits accuracy to \(\pm\)6~mm & \warnmark & Unfixable in software --- approach from one direction, rely on jaw opening. \\
Gripper servo cooks while holding & \warnmark & Compliant jaw tips + \code{REL} to detach after a grip is established. \\
Arm driven into the table & \warnmark & Firmware clamps independently of the PC; software validates every waypoint. \\
Print tolerances bind the joints & \warnmark & 0.2~mm nominal clearance; print a tolerance coupon first. \\
Servo buzz at rest & \okmark & Detach on idle via \code{REL} --- cosmetic. \\
PLA creep under sustained load & \okmark & Deflection is 0.075~mm at 5\% of yield --- don't park extended for days. \\
\bottomrule
\end{tabular}
\end{center}

% =======================================================================
\section{Build timeline}
% =======================================================================

Assumes 6--10~h/week alongside coursework.

\begin{center}
\small
\begin{tabular}{@{}cp{2.6cm}p{3.6cm}p{6.4cm}@{}}
\toprule
\textbf{Week} & \textbf{Phase} & \textbf{Output} & \textbf{Done when} \\
\midrule
0 & Requirements & This guide, signed off & Configuration chosen, order placed \\
1--2 & Mechanical design & SolidWorks parts + assembly & Assembly rebuilds cleanly when $L_1$ changes \\
2--3 & Print & \textasciitilde20 parts, 300~g & Everything fits without a file; budget 2 revisions \\
3 & Assembly + wiring & Arm on the desk & Every joint moves freely by hand \\
4 & Firmware & Serial protocol, limits, slew & Each joint sweeps its range without binding \\
5 & Kinematics + calibration & Python layer, \code{arm.py} & \code{move\_to()} lands within $\pm$8~mm \\
6 & Testing & Payload, repeatability, thermal & Picks and places a pen 10 times running \\
7 & Documentation & README, docs/, CAD exported & Someone else could rebuild it from the repo \\
\bottomrule
\end{tabular}
\end{center}

\textbf{6--8 weeks part-time.} Phase 5 calibration is where schedules slip --- per-servo microsecond offsets take a patient evening.

% =======================================================================
\section{V1 $\to$ V2 roadmap}
\label{sec:v2}
% =======================================================================

Nothing here gets built now --- it is recorded so V1's decisions do not close a door V2 needs open.

\begin{center}
\small
\begin{tabular}{L{2.3cm}L{5.0cm}L{1.1cm}L{5.6cm}}
\toprule
\textbf{Stage} & \textbf{Adds} & \textbf{Cost} & \textbf{Touches V1?} \\
\midrule
2.1 Eyes & USB webcam on a printed overhead mast & \$0--15 & One new printed part \\
2.2 Desk-plane calibration & Four-point homography: pixels $\to$ desk coords & \$0 & New module --- the whole coordinate problem, since the desk is flat \\
2.3 Detection & YOLO / colour-contour detector $\to$ centroids & \$0 & New module \\
2.4 Agent & LLM with \code{arm.pickup()}/\code{arm.place()} as tools & \$0 & \textbf{Nothing} --- same six calls the CLI uses \\
\bottomrule
\end{tabular}
\end{center}

\textbf{Three decisions V1 makes on V2's behalf}, each free now and expensive to retrofit: the PC holds intelligence and the MCU holds safety, so an agent physically cannot exceed a joint limit; the arm's public API is Cartesian, so vision output plugs straight in; the base plate has camera-mast mounting provision, so the camera-to-robot transform calibrates once and stays valid.

``Pick up my screwdriver and put it beside my laptop'' resolves to: detect $\to$ centroid $\to$ homography $\to$ \code{arm.pickup(x,y,z)} $\to$ agent picks a target $\to$ \code{arm.place(x',y',z')}. Every step after the homography is V1 code that already works.

\subsection{Payload upgrade path --- gearmotors + encoders (a separate track)}
A different axis from the AI stages above: actuation/payload, not perception. Not part of ``V2'' as the brief scoped it (vision/AI on an \emph{unchanged} chassis) --- recorded separately so it is not implied by, or confused with, the AI stages. Hobby servos are closed-loop internally and absolute-position at power-on; DC gearmotors are not, so this swap needs an encoder + PID position loop per joint in firmware (new work, not a config change), a homing routine (reversing the ``servos are absolute-position, no limit switches needed'' decision in \S\ref{sec:elec}), a motor driver per joint in place of direct PWM-to-servo wiring, a power budget redone from scratch (\S\ref{sec:power}), and a new mechanical design sized for gearmotor+gearbox envelopes rather than micro servos. What does \emph{not} change: \code{robot.arm.Arm}'s six public calls and the Cartesian API contract, since that boundary was already drawn actuator-agnostic. Not scoped or budgeted yet --- needs its own design review (motor/gear/encoder/driver selection) before it is a real plan, the same gate V1 went through in \S\ref{sec:req}.

% =======================================================================
\section{Decision gate}
% =======================================================================

Four answers, recorded, that unlock implementation:

\begin{enumerate}
\item \textbf{Configuration B} --- built up from A rather than starting at D.
\item \textbf{SG90 slaved wrist: in} --- \$3 and 17~g for level jaws in every pose.
\item \textbf{University sourcing assumed} for controller, bench supply, fasteners, wire, bearings, filament; MG996R pair and MG90S/SG90 budgeted as purchases.
\item \textbf{315~mm / 55~g} is the design target --- no known heavier payload requirement.
\end{enumerate}

\vspace{0.4cm}
\noindent\textcolor{armgrey}{\small Every figure in this guide is reproduced by \code{calculations/engineering_calcs.py} (self-checking against the values above) and \code{software/robot/kinematics.py} (FK/IK round-trip self-test). Servo ratings are published manufacturer specs for generic parts --- verify against what you actually receive, since MG996R quality varies between sellers.}

\end{document}

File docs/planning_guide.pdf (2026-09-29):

CAD $50–70 target • $100 ceiling • 3D-printed • SolidWorks

# Desk Arm

## A Low-Cost 3-DOF Desktop Robot Arm

## V1 Design & Planning Guide

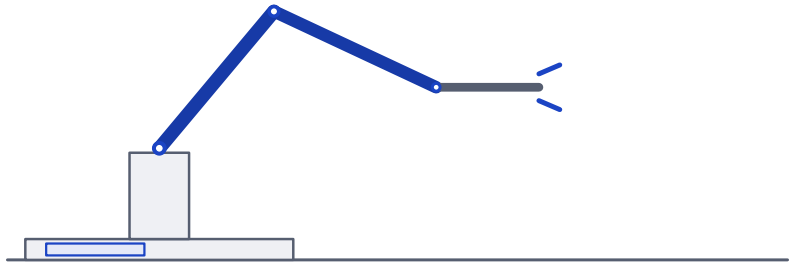
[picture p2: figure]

R max = 315 mm

Configuration B — Recommended

315 mm reach • 55 g payload • shoulder safety factor 2.44 • ~CAD $59

Prepared as the Phase 1 design review and build reference. Engineering numbers verified against calculations/engineering_calcs.py. September 29, 2026

Desk Arm V1 — Planning Guide | CONTENTS

## Contents

1 Executive summary | 3
2 Requirements | 3
3 Architecture | 4
4 Geometry | 5
5 Actuator selection | 6
6 Base stability | 7
7 Kinematics | 8
8 Electronics | 9
9 Power system | 10
10 Software architecture | 11
11 Mechanical design and printing | 11
12 Bill of materials | 13
13 Configuration comparison | 14

Desk Arm V1 — Planning Guide | CONTENTS
14 Component fallbacks | 15
15 Design risks | 16
16 Build timeline | 16
17 V1 → V2 roadmap | 16
18 Decision gate | 17

Desk Arm V1 — Planning Guide | 2 REQUIREMENTS

## 1 Executive summary

Build Configuration B. Direct-drive revolute arm, equal 120 mm links, 315 mm reach, 55 g design payload. MG996R at the shoulder and elbow, MG90S at the base and gripper, an SG90 slaved as a wrist leveller, ESP32 over USB serial. Worst-case shoulder safety factor is 2.44. Purchase cost ~CAD $59 with typical university-lab sourcing ($93 worst case, buying everything — still under the $100 ceiling).

Two things the arithmetic changes about the design, not just describes:

- The base tips over without ballast. 224 g of moving arm on a 211 mm lever beats a 269 g base on a 90 mm lever (tipping safety factor 0.89). A 400 g ballast cavity in the base plate fixes it (safety factor 2.22) — see §6.
- Do not thicken the printed links. Tip deflection is 0.075 mm against ~6 mm of servo backlash — the structure is already about 80× stiffer than the servos it is bolted to. Added material there costs shoulder margin for no measurable stiffness benefit — see §11.

Configuration A (ultra-budget, 275 mm reach, $48–55) is viable but saves only ~$8 over B for a materially smaller robot. Configuration D (stronger actuators, $85–95) is not justified — every joint in Configuration B already clears the SF ≥ 2.0 floor with margin. Full comparison in §13.

## 2 Requirements

### 2.1 Scope

V1 is a mechanically and electronically functional 3-DOF arm, controlled manually or programmatically from a PC over USB. No camera, no vision, no AI agent — that is V2 (§17), and V1’s software is only required not to block it.

### 2.2 Degrees of freedom

1. Base yaw — rotates the whole arm about a vertical axis.
2. Shoulder — raises/lowers the upper arm in the vertical plane the base currently points at.
3. Elbow — folds the forearm relative to the upper arm, same plane.
4. Gripper (not a positioning DOF) — opens/closes a two-finger claw.
5. Wrist pitch — present in hardware (an SG90) but not an independently commanded axis. Firmware slaves it to −(θ1 + θ2) so the gripper stays level in every pose (§7).

This is a positioner with 3 controllable spatial DOF (x, y, z) plus grip — matching the brief exactly, no more.

### 2.3 Target dimensions

Parameter | Target (brief) | Chosen
Base footprint | 150–200 mm | 180 × 180 mm
Reach | 250–350 mm | 315 mm kinematic / 290 mm practical
Overall height | 250–400 mm | ~340 mm (arm vertical, incl. gripper)

Link lengths: shoulder height h0 = 75 mm, upper arm L1 = 120 mm, forearm L2 = 120 mm, wrist→TCP L3 = 75 mm. Equal L1 = L2 is deliberate — see §4.

Desk Arm V1 — Planning Guide | 3 ARCHITECTURE

### 2.4 Payload and workspace

Design payload: 55 g at full 315 mm reach — pens, small tools, USB sticks, small project boxes, small electronics.

Bound | Value | Set by
Outer radius | 315 / 290 mm | Link length / IK conditioning near full extension
Inner radius | 130 mm | Forearm-to-turret collision
Floor | z = 10 mm | Jaw-to-table clearance, enforced in firmware
Ceiling | z = 315 mm | Arm vertical
Base sweep | ±90◦ | No slip ring in V1

Usable desk area: an annular sector, 130–290 mm radius, 180° — about 0.09 m² directly in front of the base.

### 2.5 Budget

Target personal spend CAD $50–70; absolute maximum CAD $100. Configuration B lands at ~$59 with typical lab sourcing, ~$93 buying everything. Full breakdown in §12.

### 2.6 Decision gate

Four questions, answered before any implementation started:

1. Configuration B, built up from A rather than starting at D.
2. SG90 slaved wrist: in. $3 and 17 g buys a level gripper in every pose.
3. University sourcing: assume lab-available for controller, bench power supply, fasteners, wire, bearings, filament; budget the MG996R pair and MG90S/SG90 as purchased.
4. 315 mm / 55 g is the right target — no known heavier payload requirement.

## 3 Architecture

Serial revolute arm — the classic RRR shoulder–elbow chain on a rotating turret. Base yaw is the only vertical axis; shoulder and elbow work in a single vertical plane the base sweeps around. This is the simplest structure that reaches every point on a desk, and the kinematics collapse to one trig problem.

Axis | Type | Range | Actuator Notes
1 — Base yaw | Revolute, vertical | −90◦
. . . + 90◦ | MG90S | Turret on 2×608ZZ bearings

2 — Shoulder Revolute,
| horiz. | 0

◦

. . . 110◦ | MG996R | Highest-loaded joint
3 — Elbow | Revolute, horiz. | −130◦ . . . 0
- | MG996R | Elbow-up solution only
Wrist (slaved) | Revolute, horiz. | −120◦
. . . + 30◦ | SG90 | Firmware-computed, not
| | | commanded
Gripper | Two-finger, meshed
0–55 mm | MG90S | Compliant tip

### 3.1 Why a slaved wrist rather than a parallelogram linkage

A three-DOF positioner has exactly enough freedom to hit an (x, y, z) target and none left over — gripper pitch is whatever the IK happens to produce, swinging roughly 30° across the workspace.

Desk Arm V1 — Planning Guide | 4 GEOMETRY

Three ways to fix that:

Twin parallelogram
Two four-bar linkages hold the jaws level with no extra servo, and move the elbow actuator to the turret. Elegant, but six more printed parts and twelve more pivots with slop at every one. Deferred.

SG90 slaved wrist — chosen
One extra micro servo, driven by firmware as a dependent axis. Costs ~$3 and 17 g at 250 mm, which drops shoulder SF from 2.57 to 2.44 — cheap for level jaws.

Fixed bracket
Bolt the gripper on at a fixed 45°. Zero cost, zero parts, works if objects are always approached from the side. Configuration A fallback.

All three bolt to the same 24×24 mm wrist mounting face on the forearm — start with the fixed bracket, add the SG90 later, try the linkage after that, without touching another part in the assembly.

## 4 Geometry

Equal-length links, L1 = L2 = 120 mm — deliberate, not arbitrary: equal lengths make the printed parts nearly identical (one parametric sketch, two configurations), maximise the foldedto-extended reach ratio, and put the workspace’s inner boundary where the turret already is. Every dimension traces back to the torque budget in §5.

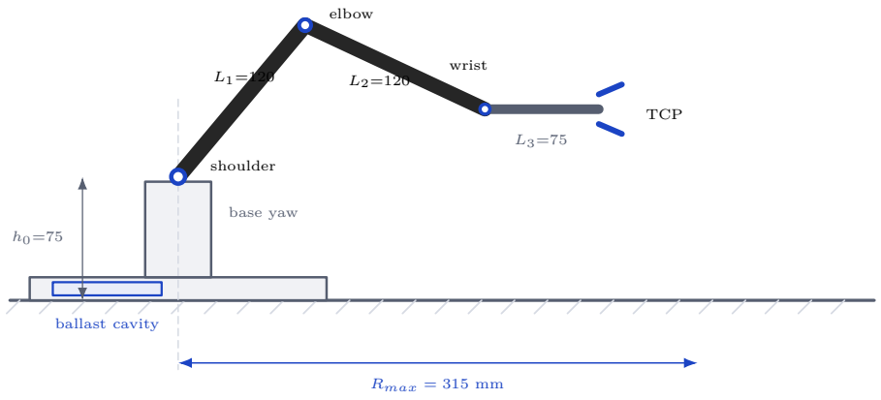
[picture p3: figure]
ballast cavity; shoulder; elbow; wrist; TCP; base yaw; Rmax = 315 mm

Figure 1: Side elevation, 1 px = 1 mm, arm shown mid-stroke. The wrist stays level in every pose, so L3 is a purely horizontal offset in the kinematics.

Parameter | Value | Rationale
Shoulder height h0 | 75 mm | Elbow folds without hitting the turret
Upper arm L1 | 120 mm | Torque-driven — 140 mm drops shoulder SF below
| | 2.1
Forearm L2 | 120 mm | Equal to L1 — same printed profile
Wrist→TCP L3 | 75 mm | Jaw depth + clearance for a 30 mm object
Max TCP reach | 315 mm | Within the 250–350 mm brief
Base footprint | 180×180 mm | Drives the tipping calculation, §6
Jaw opening | 0–55 mm | Pen through small project box

Desk Arm V1 — Planning Guide | 5 ACTUATOR SELECTION

## 5 Actuator selection

### 5.1 Method

Static gravity-holding torque at the worst-case pose (fully extended, horizontal — also the normal working pose for a desk arm reaching across the table). Dynamic terms are small at the speeds this arm moves at (under 10% of the gravity term at the firmware’s 60°/s slew limit) and are absorbed by the safety-factor floor rather than modelled explicitly. Target safety factor: ≥ 2.0, evaluated at 6.0 V rated torque — roughly the point below which a hobby servo holding a static pose runs hot instead of idling near stall current.

### 5.2 Mass budget

Horizontal distance from the shoulder axis, arm fully extended — the worst case for every load in the chain. Verified by calculations/engineering_calcs.py.

Item | Mass | Distance | Moment
Upper-arm link pair + spacers | 30 g | 60 mm | 1,800 g·mm
Elbow servo (MG996R) + bracket | 65 g | 120 mm | 7,800 g·mm
Forearm link pair + spacers | 25 g | 180 mm | 4,500 g·mm
Wrist servo (SG90) + bracket | 17 g | 250 mm | 4,250 g·mm
Gripper assembly (MG90S + jaws) | 32 g | 285 mm | 9,120 g·mm
Design payload | 55 g | 320 mm | 17,600 g·mm
Moving assembly total | 224 g CoM 201 mm 45,070 g·mm

Below the shoulder (drives base stability, not shoulder torque): base plate 100 g, column + turret 60 g, base servo 14 g, shoulder servo 55 g, hardware 40 g → 269 g.

The elbow servo alone is 29% of the moving mass, sitting at the point in the chain where moving it costs the most shoulder torque — the highest-leverage future change, if shoulder margin ever becomes a problem, is relocating it to the turret behind a linkage (~1.4 kg·cm), not implemented in V1.

### 5.3 Torque calculations

Shoulder: τ1 = g

∑

i

midi = 9.81 × 0.04507 kg m = 0.442 N m = 4.51 kg·cm

Elbow: τ2 = 9.81 × (0.025×0.060 + 0.017×0.130 + 0.032×0.165 + 0.055×0.200) = 9.81 × 0.01999 = 0.196 N m = 2.00 kg·cm

Base yaw: τ0 ≈ Iα + drag = 0.0056 × 3.5 + drag ≈ 0.30 kg·cm

Wrist: τ3 = g [0.032(0.285−0.240) + 0.055(0.320−0.240)] = 0.057 N m = 0.58 kg·cm

Desk Arm V1 — Planning Guide | 6 BASE STABILITY

### 5.4 Servo table

Joint | Servo | Req. Target ×2 | Rated @6V SF
Base | MG90S | 0.30 | 0.60 | 2.20 7.34 OK
Shoulder | MG996R (sizing joint) | 4.51 | 9.02 | 11.00 2.44 OK
Elbow | MG996R | 2.00 | 4.00 | 11.00 5.50 OK
Wrist (slave) SG90 | 0.58 | 1.17 | 1.80 3.08 OK
Gripper | MG90S | 0.82 | 1.64 | 2.20 2.70 OK

All kg·cm. On a 5 V supply the MG996R drops to ~9.4 kg·cm and shoulder SF falls to 2.08 — still acceptable, which is why a 5 V/3 A phone charger is a legitimate power fallback (§9).

Why the elbow is over-specified (SF 5.50), deliberately: it needs 2.00 kg·cm, so at SF 2 it needs 4.0. The MG90S tops out at 2.2 and fails. The next rung up, an MG92B at 3.5 kg·cm (~$8), still gives only SF 1.75 — and costs more than an MG996R. The MG996R wins by default and the margin is free.

### 5.5 Gripper: SG90 vs MG90S

Required clamp force for a 55 g object, µ = 0.5 (rubber pad, conservative): mg/2µ = 0.54 N. Design target: 4 N per jaw — about 7× the physics minimum, because real grips are off-centre and objects get bumped.

Jaw pivot torque = 4.0 N × 0.030 m = 0.12 N m Servo torque (1.5:1 reduction) = 0.12/1.5 = 0.080 N m = 0.82 kg·cm

| SG90 | MG90S (chosen)
Mass / cost | 9 g / ~$2 | 13.4 g / ~$6
Gears | Nylon — strips on a hard stall | Metal — survives stalls/knocks
Footprint | 22.8×12.2×22.5 mm, 32 mm span | Identical — drop-in either way

Both pass on torque. The decision is about what happens the twentieth time the gripper closes on something it cannot close on — metal gears survive it, nylon eventually strips. The identical footprint means the mount is one printed part regardless of which servo goes in it.

Mechanism: two mirror-image printed jaws on M3 pins with meshed gear sectors (module 1.5, ~10 teeth engaged) — one servo drives one jaw, the sectors force the other to mirror it. Self-centring, cannot desync. Jaw faces carry a 90° V-groove plus a rubber pad. Compliance matters more than gear material: thin the last 12 mm of each jaw to 1.6 mm so it flexes ~1 mm under load — one commanded “closed” angle then grips a range of object sizes without ever driving the servo into a hard stall.

## 6 Base stability

Tipping about the front edge of the base plate, arm fully extended, payload at maximum reach. The shoulder axis sits 10 mm forward of the base axis, so the moving CoM is 211 mm out.

Desk Arm V1 — Planning Guide | 7 KINEMATICS

Mover = 0.224 × 9.81 × (0.211 − 0.090) = 0.266 N m

Mrest, no ballast = 0.269 × 9.81 × 0.090 = 0.238 N m | ⇒ SF = 0.89 fails
Mrest, +400 g ballast = 0.669 × 9.81 × 0.090 = 0.591 N m | ⇒ SF = 2.22 OK

The arm as drawn tips over. 224 g on a 211 mm lever beats a 269 g base on a 90 mm lever, and no amount of careful printing fixes that — it is easy to miss on paper because the whole robot only weighs ~500 g.

### 6.1 Fixes

Ballast the base — primary
Seal a 66×66×18 mm cavity into the base plate with a snap lid. Fill with washers, sand, or spare screws. 400 g minimum, 500 g preferred. Costs nothing and lowers the CoM as well as raising the mass.

Park the supply on the plate
A 6 V 3 A brick weighs 150–250 g. Recessed behind the column, it becomes free ballast plus shorter power leads.

Clamp it down — optional
Two 8 mm slots at the rear take a small C-clamp. Makes tipping structurally impossible, worth having for fast moves, but should not be the only thing keeping the arm upright.

Dynamic loading is worse than this static calculation. Decelerating the arm at the end of a fast reach adds an inertial term this analysis ignores — the target is SF 2.2, not 1.2, and firmware slew-limits every joint to 60°/s for exactly this reason.

## 7 Kinematics

No DH tables, no Jacobians, no numerical solver. Base rotation decouples completely from shoulder/elbow, leaving a two-link planar problem with a closed-form solution — implemented in software/robot/kinematics.py (~40 lines including workspace checks, with a self-test that reproduces every number in this section).

### 7.1 Forward kinematics

r = L1 cos θ1 + L2 cos(θ1+θ2) + L3 z = h0 + L1 sin θ1 + L2 sin(θ1+θ2)

x = r cos θ0 y = r sin θ0

L3 adds directly to r with no trig term — the payoff of the levelled wrist. Without it, L3 would carry a cos(θ1+θ2+θ3) factor and the inverse problem stops being closed-form.

Desk Arm V1 — Planning Guide | 8 ELECTRONICS

### 7.2 Inverse kinematics

θ0 = atan2(y, x)

r

′ =

√
x

2 + y

2 − L3 | z ′ = z − h0

D =

r

′2 + z

′2 − L
2
1 − L
| 2
| 2
2L1L2 | (unreachable if |D| > 1, checked before acos)
θ2 = − arccos(D) | (negative root = elbow-up)

θ1 = atan2(z

′

, r′

) − atan2(
| L2 sin θ2, L1 + L2 cos θ2

)

θ3 = −(θ1 + θ2) (slaved wrist, jaws level)

The two arccos roots are elbow-up and elbow-down. Elbow-down puts the elbow below the table on nearly every desk-height target, so the solver takes the negative root unconditionally.

### 7.3 Validation order, before anything moves

1. Reachability — |D| ≤ 1 and 130 ≤

√
| x 2 + y 2 ≤ 290 mm.
2. Joint limits — every θ inside its mechanical range (§3.2).
3. Table clearance — z ≥ 10 mm, and the elbow itself above the table.
4. Path check — for a Cartesian move, interpolate 20 waypoints and validate each; a straight line between two legal poses can pass through an illegal one.

The accuracy limit is backlash, not mathematics. An MG996R has 1–2° of gear lash plus potentiometer deadband. At the 240 mm shoulder+elbow lever, 1.5° is 6 mm at the gripper. Expect ±5–8 mm repeatability and design around it: approach every target from the same direction, and let the 55 mm jaw opening absorb the rest. No amount of IK precision buys back a millimetre of this.

## 8 Electronics

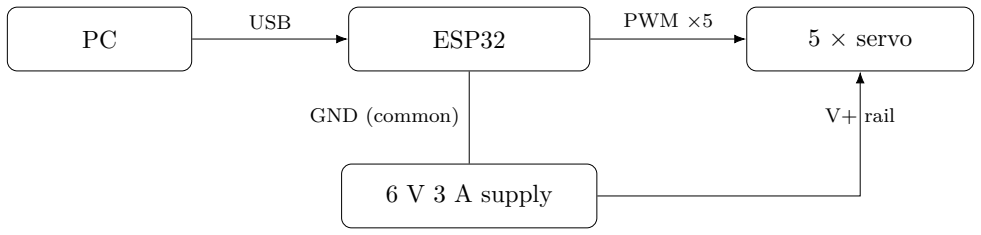
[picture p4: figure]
ESP32; 5 × servo; 6 V 3 A supply; USB; PWM ×5; GND (common); rail

### 8.1 Controller: ESP32 (DevKitC or equivalent)

Full pin-out, colour-coded nets and the grounding/power checklist below are also drawn out as a standalone diagram, wiring_diagram.svg, alongside this guide. Revised from an original Arduino Nano choice. The Nano’s advantage was native 5 V logic — hobby servos want a 5 V pulse, and a 3.3 V board introduces a question with no clean answer on paper: some servos latch reliably on 3.3 V, some jitter, and the difference only shows up after assembly. In practice, the SG90/MG90S/MG996R family used here decodes PWM through an analog RC input stage that a 3.3 V high clears — a well-worn combination, not a gamble. Test each servo before final assembly; the documented fallback for a unit that jitters is a 74HCT125/74AHCT125 quad buffer (~$1, covers all five signal lines), not a controller change. In exchange for accepting that one check: a dual-core chip with far more flash/RAM/GPIO than this project needs, a similar street price to the Nano, and Wi-Fi/BT already on board if a future V2 ever wants the arm untethered (unused,

Desk Arm V1 — Planning Guide | 9 POWER SYSTEM

not required, by docs/v2_ai_roadmap.md). Requires the ESP32Servo library in place of the stock Servo.h (the ESP32 Arduino core ships neither) — the attach()/writeMicroseconds() API is unchanged, it just rides the chip’s LEDC PWM peripheral instead of a hardware timer.

Deliberately not included: a PCA9685 driver board (five servos fit on five ESP32 GPIOs already — the board solves a problem that starts around twelve servos); encoders or current sensing (hobby servos have no position-feedback path to expose); limit switches (servos are absolute-position devices and already know where they are at power-on).

Fallback: an Arduino Nano/Uno remains a straightforward substitute if an ESP32 isn’t available, or a servo won’t settle at 3.3 V even behind a level shifter — same pin roles, same serial protocol, swap ESP32Servo back for stock Servo.h and drop the timer-allocation calls in setup().

### 8.2 Serial protocol

ASCII, line-oriented, one command per line, every command answered.

Command | Reply | Purpose
PING | OK ARM v1 | Port identification and liveness
J <base> <sh> <el> | OK / ERR LIMIT
<joint>

Absolute joint angles, degrees

G <0-100> | OK | Gripper, 0 closed, 100 open
US <ch> <us> | OK / ERR RANGE | Raw pulse, ch=B/S/E/W/G,
calibration only
HOME | OK | Slew to the safe folded pose
STOP | OK | Freeze at the current position
REL | OK | Detach all servos
STAT | angles + us | Current commanded state

The split is deliberate: the firmware owns safety, the PC owns intelligence. Joint limits and slew limiting live on the ESP32 and cannot be bypassed by a buggy Python script — or, later, a confused AI agent.

## 9 Power system

Servo | Qty | Idle | Moving | Stall
MG996R | 2 | 0.17 A | 0.6–0.9 A | 2.5 A
MG90S | 2 | 0.08 A | 0.2–0.4 A | 0.7 A
SG90 | 1 | 0.06 A | 0.2 A | 0.65 A
Rail total | 5 0.56 A 1.2–1.8 A 7.05 A

The 7.05 A all-stall figure is not a design case — it requires every joint jammed simultaneously. The design case is 1.8 A continuous, ~3.5 A transient at direction reversals.

Specification: 6.0 V, 3 A regulated (18 W), barrel jack, 3 A fuse. 6.0 V because MG996R torque is quoted at 6 V; at 5 V shoulder SF falls from 2.44 to 2.08. Bulk capacitance: 2×1000 µF at the servo headers. C∆V /I = 2000 µF × 0.5V/2A = 0.5 ms — enough to kill a switching spike, not a substitute for a supply that can source the current.

Rejected: 4×AA batteries. Nominal voltage is fine — 4 fresh alkaline cells land around 6.4 V, inside the 4.8–6.6 V window — but internal resistance is not: alkaline AAs run ~0.15–0.3 Ω each,

Desk Arm V1 — Planning Guide | 11 MECHANICAL DESIGN AND PRINTING

so ~0.6–1.2 Ω for the pack. At the 1.8 A design-case draw that is 1.1–2.2 V of sag before the 3.5 A transient case makes it worse — the same failure mode as the capacitor note above, a source that cannot hold voltage under real load. NiMH cells have lower internal resistance and are the better chemistry if a battery pack is ever used for real, but even then treat it as good for a single-joint bench check, not for running the assembled arm.

Three rules, each of which has ended someone’s project: never feed the servo rail from the ESP32’s 5V/VIN pin or USB (that pin sits upstream of the board’s own 3.3 V logic regulator and reflects whatever the USB port can source, typically ~500 mA; five servos will brown it out mid-move); servo ground and ESP32 ground must be joined, or the PWM has no reference and servos twitch randomly; no 7.4 V LiPo direct to the rail — it will destroy the MG90S and SG90 within minutes.

## 10 Software architecture

Layer | Owns
firmware/arm_firmware/ (Arduino C++) | Joint limits, slew rate — safety
software/robot/ (Python) | Kinematics, trajectory, transport, the Arm API
software/cli.py, sequences.py | Manual control and demo/test routines
V2 (not built) | software/vision/, software/agent/ — add here only

The public surface everything else is meant to use — the CLI, the demo sequences, and eventually the V2 agent — is robot.arm.Arm:

arm.home()
arm.move_joints(base, shoulder, elbow)
arm.move_to(x, y, z) (Cartesian, validated, interpolated) arm.grip(percent)
arm.pickup(x, y, z)
arm.place(x, y, z)

This is the V1→V2 contract (§17): in V2 the agent does not get its own motion code, its own limits, or its own IK — it calls exactly these six methods. No ROS, no behaviour trees, no message bus — a 300 mm desk arm with five servos does not have a software problem that a Python class cannot solve.

## 11 Mechanical design and printing

Links are twin printed side plates on printed spacers — a box section that is stiff in bending, prints flat with no supports, and puts every bolt in double shear. Roughly 14 unique parts, 20 printed pieces, ~300 g of filament, 18–22 h print time.

Desk Arm V1 — Planning Guide | 11 MECHANICAL DESIGN AND PRINTING

### 11.1 Material assignment

Part | Material Why
Base, column, turret | PLA | Stiffness and flatness; not impact-loaded
Upper arm, forearm links | PLA | E ≈ 3.5 GPa vs. PETG’s 2.0 — deflection matters most
Shoulder / elbow brackets | PETG | Highest bending stress; layer adhesion matters most
Servo horn adapters | PETG | Small, bolted, loaded to peel layers apart
Gripper jaws | PETG | Designed to flex; PLA would snap at the flex section
Spacers, clips, tray | PLA | Unloaded
Ballast block | Mild steel, milled | Not printed — see below

Print settings: 0.4 mm nozzle, 0.2 mm layers, 4 perimeters, 30% gyroid, 5 top/bottom — perimeter count dominates strength in a thin printed part.

### 11.2 Ballast

A solid milled block, not loose fill — a fixed, known mass at a fixed position matches the stability calc’s assumption exactly and cannot shift the CoM as the base rotates. Mild steel, ~50–55 cm³ for the 400 g target (ρ ≈ 7.85 g/cm³
): a 60×60×15 mm block is ~424 g, clearing the minimum with margin. Steel over aluminium specifically for the footprint — aluminium (ρ ≈ 2.70) needs ~3× the volume for the same mass, and the ballast cavity already competes for space with the column and base-servo mount inside the 180×180 mm base. Weigh the actual cut block and trim (or size up the blank) to clear 400 g — mild steel density varies enough between alloys (7.75– 7.87 g/cm³
) that this is measure-don’t-assume, same as everything else safety-factor-adjacent in this guide. Bolt or press-fit it into the cavity; a block free to slide during base rotation turns a designed-in stability margin into an unmeasured one.

### 11.3 Layer orientation — three rules that decide whether this works

1. Print brackets flat, never standing up. Loaded perpendicular to the layer planes, a printed part manages only ~40–60% of its in-plane strength.
2. Every bolt hole axis is normal to the build plate. Bolts then clamp across layers in compression, not trying to split them apart.
3. Never print a servo spline. A printed 25-tooth spline will round off. Bolt the metal horn that shipped with the servo to the printed part with 2–3 M2 screws — the single most common failure mode in printed arms, designed out from part one.

### 11.4 Where FEA earns its time

Worth running (2 studies): the shoulder bracket (0.44 N m through a bolted interface, stress concentration at the servo cutout — the one part where intuition is unreliable); the upper-arm link’s elbow-servo pocket (expect the answer to be “add a 3 mm fillet”). Not worth running: everything else — the hand calculation below already answers the question.

Desk Arm V1 — Planning Guide | 12 BILL OF MATERIALS

I = 2 ×

3 × 20³

12

= 4000 mm⁴

δ =

F L³

3EI

=

1.3 × 120³
3 × 2500 × 4000

= 0.075 mm

Seventy-five microns. The structure is ~80× stiffer than the servo backlash it is bolted to (§7). Do not thicken these links — every gram added buys nothing measurable and costs shoulder safety factor directly.

### 11.5 Parametric strategy

One global variables file drives L1, L2, L3, h0, plate thickness and pin diameter across every part. A servo-pocket library feature with a two-row design table (standard: MG996R-class, 40.7×19.7×42.9 mm; micro: MG90S/SG90-class, 22.8×12.2×22.5 mm) means swapping servo sizes is a configuration change, not a redesign — this is what makes Configurations A–D one robot instead of four. 0.2 mm nominal clearance on every pin and pocket, tuned once via a printed tolerance coupon. Full part list and file layout in cad/README.md.

## 12 Bill of materials

### 12.1 BOM A — purchase

Item | Qty Cost | Likely in a lab?
MG996R servo | 2 | $17 | Unlikely
MG90S servo | 2 | $13 | Maybe
SG90 servo | 1 | $3 | Likely
6 V 3 A adapter + barrel jack | 1 | $14 | Likely (bench PSU substitutes)
ESP32 DevKit (CP2102/CH340) | 1 | $12 | Maybe — a Nano works as a $9 fallback
1000 µF 16 V electrolytic ×2 | 1 | $3 | Very likely
608ZZ bearing ×2 | 1 | $4 | Likely
M3 screw/nyloc assortment | 1 kit | $11 | Very likely
Dupont wire + perfboard | 1 | $8 | Very likely
PLA + PETG filament (~300 g) | — | $8 | Likely
Buy absolutely everything | | $93 | under the $100 ceiling

Optional, not in the total above: a 74HCT125/74AHCT125 level shifter (~$1) if a servo jitters on the ESP32’s 3.3 V signal (§9) — most builds won’t need it.

Desk Arm V1 — Planning Guide | 13 CONFIGURATION COMPARISON

### 12.2 BOM B — university-sourced

Component | Saves Substitution risk

Microcontroller (ESP32, or
Uno/Nano/Mega/Pico fallback)

$12 Low — confirm servo signal quality

Power supply (bench PSU) | $14 None — better for testing
Fasteners (workshop M3 stock) | $11 None
Wiring, headers, perfboard | $8 None
Bearings (mechanism-lab stock) | $4 Low
Filament (makerspace stock) | $8 None
Capacitors | | | $3 None
Micro servos (teaching kits) | $16 Check for stripped gears first
MG996R ×2 | $17 Plan to buy — unlikely on the
| | | shelf
Ballast stock (mild steel remnant, milled to
size, §11)

$5–8 Low — any mild steel blank
| | | ≥55 cm³ works

### 12.3 Cost summary

Scenario | Cost
Buy everything (worst case) | $93
Typical student (servos + supply + filament, rest sourced) | $59
Well-stocked lab (MG996R + MG90S only) | $33
AliExpress route (buy-everything, 3-week wait) | $42

The $59 typical-student figure is unaffected by the ESP32 swap — the controller is lab-sourced in that scenario either way. The AliExpress total moves by only $1 despite the $3 Amazon.ca delta, since ESP32 dev boards are inexpensive there too, often $5–6.

## 13 Configuration comparison

| A — Ultra-budget | B — Recommended

C — University D — Stronger

Purchase cost $48–55 | $55–65 | $17–35 | $85–95
Reach | 275 mm | 315 mm | 315 mm | 315 mm
Payload | 30 g | 55 g | 55 g | 80 g
Base | SG90 | MG90S | lab micro servo | MG90S
Shoulder | MG996R | MG996R | MG996R | DS3218 (20 kg·cm)
Elbow | MG90S | MG996R | MG996R | MG996R
Gripper | SG90 | MG90S | MG90S | MG90S
Wrist | fixed bracket | SG90 slaved | SG90 slaved | MG90S slaved
Shoulder SF | 4.1 | 2.44 | 2.44 | 4.0
University components | minimal | minimal | high | optional

Every column is the same robot: same CAD files, same assembly, same firmware, same Python. A→B is a 40 mm forearm configuration change and two servo swaps. B→D is one servo and a different mounting plate.

Desk Arm V1 — Planning Guide | 14 COMPONENT FALLBACKS

### 13.1 Decision trail

G1 — Can the cheapest configuration meet torque requirements?
Yes, but only at 275 mm reach and 30 g payload — satisfies torque by shrinking the robot to the low end of the brief’s range. Conditional pass.

G2 — Can university components close the gap at zero cost?
Partly — ~$45 of the BOM is plausible lab stock, but MG996R-class servos usually are not. Partial.

G3 — Is the step from A to B worth its cost?
Yes, decisively: $8 buys +40 mm reach, +25 g payload, and a levelled wrist. Configuration B selected.

G4 — Does B leave enough margin, or is D required?
Every joint clears SF 2.0. A DS3218 would add $18 to fix a problem that does not exist. Configuration D not required.

## 14 Component fallbacks

Component | Primary | If unavailable | If too weak | University
Shoulder | MG996R | MG995 | DS3218 | Any 9–20 kg·cm servo
Elbow | MG996R | MG90S + L2=80mm | 2nd MG996R | Standard-frame servo
Base | MG90S | SG90 | MG996R | Any micro servo
Gripper | MG90S | SG90 + lighter jaws | MG92B | Check for stripped gears
Wrist | SG90 | fixed 45° bracket | MG90S | Any micro servo
Controller | ESP32 | Nano/Uno (5V) | — | ESP32/Uno/Nano/Pico
Power | 6V 3A adapter | 5V 3A charger (−15%) | 6V 5A adapter | Bench supply

### 14.1 Geometry fallback — apply strictly in this order

1. Cut the payload — 55 g→30 g removes 39% of the shoulder moment for free.
2. Shorten the forearm — L2 120→80 mm, reach falls to 275 mm.
3. Lighten the prints — 3 mm→2.5 mm plates, 30%→20% infill; ~12 g saved, deflection stays under 0.15 mm.
4. Only then, a bigger servo — and re-check steps 1–3 first.

A 350 mm arm at 55 g needs ~5.4 kg·cm at the shoulder — an MG996R right at the edge, or $18 more for a DS3218. The 315 mm arm clears 4.51 comfortably on the $8 servo. 35 mm of reach is not worth doubling the actuator budget.

## 15 Design risks

Desk Arm V1 — Planning Guide | 17 V1 → V2 ROADMAP
Risk | Severity Mitigation

Printed servo-horn interface
strips
fails | Never print splines — bolt the metal horn on. De-
signed in from part one.
Base tips forward | fails | 400 g ballast cavity + supply on the plate (§6).
Verify by hand before power-on.
Brownout resets mid-move | fails | Separate 3 A servo rail, common ground,
2×1000 µF, never the ESP32’s 5V/VIN pin. Servo jitters on ESP32’s 3.3 V
signal

watch Test each servo before final assembly; add a 74HCT125 level shifter (~$1) on that signal line, or fall back to a Nano (§12) — see §Controller in Electronics.
Backlash limits accuracy to ±6 mm

watch Unfixable in software — approach from one direction, rely on jaw opening. Gripper servo cooks while
holding

watch Compliant jaw tips + REL to detach after a grip is established.
Arm driven into the table | watch | Firmware clamps independently of the PC; soft-
ware validates every waypoint. Print tolerances bind the
joints

watch 0.2 mm nominal clearance; print a tolerance coupon first.
Servo buzz at rest | OK | Detach on idle via REL — cosmetic.
PLA creep under sustained
load
OK | Deflection is 0.075 mm at 5% of yield — don’t
park extended for days.

## 16 Build timeline

Assumes 6–10 h/week alongside coursework.

Week Phase | Output | Done when
0 | Requirements | This guide, signed off | Configuration chosen, order placed
1–2 | Mechanical de- sign | SolidWorks parts + as- sembly | Assembly rebuilds cleanly when L1 changes
2–3 | Print | ~20 parts, 300 g | Everything fits without a file; budget 2 re- visions
3 | Assembly | +
| wiring | Arm on the desk | Every joint moves freely by hand
4 | Firmware | Serial protocol, limits, slew | Each joint sweeps its range without bind- ing
5 | Kinematics | +
| calibration | Python layer, arm.py | move\_to() lands within ±8 mm
6 | Testing | Payload, repeatability, thermal | Picks and places a pen 10 times running
7 | Documentation | README, docs/, CAD exported | Someone else could rebuild it from the repo

6–8 weeks part-time. Phase 5 calibration is where schedules slip — per-servo microsecond offsets take a patient evening.

## 17 V1 → V2 roadmap

Nothing here gets built now — it is recorded so V1’s decisions do not close a door V2 needs open.

Desk Arm V1 — Planning Guide | 18 DECISION GATE
Stage | Adds | Cost | Touches V1?
2.1 Eyes | USB webcam on a printed overhead mast | $0–15 | One new printed part
2.2 Desk-plane calibration | Four-point homography: pixels → desk coords | $0 | New module — the whole coordinate problem, since the desk is flat
2.3 Detection | YOLO / colour-contour detector → centroids | $0 | New module
2.4 Agent | LLM with arm.pickup()/arm.place() as tools | $0 | Nothing — same six calls the CLI uses

Three decisions V1 makes on V2’s behalf, each free now and expensive to retrofit: the PC holds intelligence and the MCU holds safety, so an agent physically cannot exceed a joint limit; the arm’s public API is Cartesian, so vision output plugs straight in; the base plate has camera-mast mounting provision, so the camera-to-robot transform calibrates once and stays valid.

“Pick up my screwdriver and put it beside my laptop” resolves to: detect → centroid → homography → arm.pickup(x,y,z) → agent picks a target → arm.place(x',y',z'). Every step after the homography is V1 code that already works.

### 17.1 Payload upgrade path — gearmotors + encoders (a separate track)

A different axis from the AI stages above: actuation/payload, not perception. Not part of “V2” as the brief scoped it (vision/AI on an unchanged chassis) — recorded separately so it is not implied by, or confused with, the AI stages. Hobby servos are closed-loop internally and absolute-position at power-on; DC gearmotors are not, so this swap needs an encoder + PID position loop per joint in firmware (new work, not a config change), a homing routine (reversing the “servos are absolute-position, no limit switches needed” decision in §8), a motor driver per joint in place of direct PWM-to-servo wiring, a power budget redone from scratch (§9), and a new mechanical design sized for gearmotor+gearbox envelopes rather than micro servos. What does not change: robot.arm.Arm’s six public calls and the Cartesian API contract, since that boundary was already drawn actuator-agnostic. Not scoped or budgeted yet — needs its own design review (motor/gear/encoder/driver selection) before it is a real plan, the same gate V1 went through in §2.

## 18 Decision gate

Four answers, recorded, that unlock implementation:

1. Configuration B — built up from A rather than starting at D.
2. SG90 slaved wrist: in — $3 and 17 g for level jaws in every pose.
3. University sourcing assumed for controller, bench supply, fasteners, wire, bearings, filament; MG996R pair and MG90S/SG90 budgeted as purchases.
4. 315 mm / 55 g is the design target — no known heavier payload requirement.

Every figure in this guide is reproduced by calculations/engineering_calcs.py (self-checking against the values above) and software/robot/kinematics.py (FK/IK round-trip self-test). Servo ratings are published manufacturer specs for generic parts — verify against what you actually receive, since MG996R quality varies between sellers.

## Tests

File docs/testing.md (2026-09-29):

# Testing

Test plan by phase, with concrete acceptance criteria rather than "works
fine" — each one is checkable against a number already committed to
elsewhere in the docs.

## Individual joints (after Phase 5 firmware, before Phase 6 kinematics)

| Test | Method | Acceptance |
|---|---|---|
| Full range of motion | `J`/`G` sweep from one limit to the other, by hand-verify against `firmware/arm_firmware/limits.h` | No binding anywhere in range; firmware rejects out-of-range commands with `ERR LIMIT` |
| Slew limiting | Command a large step change, time it | Matches the 60°/s cap — protects against the tipping/inertia case in the stability calc |
| Holding current | Bench-supply ammeter, joint at rest at a legal angle | Reads near the "idle" column in `docs/power_system.md`'s current table, not "moving" or "stall" |
| Detach | `REL`, then move joint by hand | Moves freely, no resistance beyond gear friction |

## Full arm

| Test | Method | Acceptance |
|---|---|---|
| HOME | `HOME` from an arbitrary pose | Reaches the folded pose without collision, arm clears the table |
| Workspace boundary | `move_to()` at the documented inner/outer radius (130 / 290 mm) and just outside it | Inside: succeeds. Outside: rejected before any servo moves (`docs/kinematics.md` validation order) |
| Table clearance | `move_to()` targeting `z` below 10 mm | Rejected by the software floor, not just the firmware — both layers should refuse it |
| Path safety | A Cartesian move whose straight-line path dips through an illegal region | Rejected, even though start and end poses are individually legal |
| Repeatability | `move_to()` the same target 10× from the same approach direction, measure with a ruler | Within ±5–8 mm (the backlash-limited figure in `docs/kinematics.md`) — if it's worse, recheck calibration before assuming a mechanical fault |

## Gripper

| Test | Method | Acceptance |
|---|---|---|
| Jaw opening | `G 0` → `G 100` | 0–55 mm as designed |
| Grip force | Compliant-tip jaw closes on a range of object widths at one commanded angle | Holds a 55 g object at full reach without the servo audibly stalling |
| Stall behaviour | Command `G 0` (closed) on an object too large to fully close on | Servo current rises but the compliant jaw tip flexes rather than the servo grinding at stall indefinitely — send `REL` if holding for more than a few seconds |

## Payload

- Sweep the design payload (55 g) through the full workspace at several
  representative points (near, far, left, right of centre).
- Confirm no joint's holding current approaches its stall figure
  (`docs/power_system.md`) at any tested point — if one does, that's the
  "measured, not predicted" trigger for the B→D fallback in
  `docs/requirements.md`.
- Repeat at 0 g (no payload) to get a baseline — the difference isolates
  payload-driven current from friction/binding.

## Stability

- With the base ballasted per `docs/mechanical_design.md`, extend the arm to
  full reach horizontally with the design payload and check the base does
  not lift at the front edge.
- Repeat during a fast HOME→extended move (the dynamic case the static
  calculation doesn't cover) — this is why the slew limit exists; if the
  base rocks noticeably, the 60°/s cap may need to come down for large
  moves specifically.

## Servo heating / current (thermal soak)

- Run a 10-minute repeated pick-and-place sequence (`software/sequences.py`)
  at the design payload.
- Check each servo case temperature by hand periodically — warm is normal,
  too hot to touch briefly is not.
- Log current draw over the run if the bench supply supports it; a rising
  idle-current trend at a fixed pose usually means a joint is being asked to
  hold against a growing mechanical bind (heat-related dimensional
  creep in a printed part is the usual cause) rather than an electrical
  fault.

## Regression checklist before calling V1 done

- [ ] All individual-joint tests pass
- [ ] `move_to()` repeatability measured and recorded (update
      `docs/kinematics.md` with the actual number if it differs materially
      from the ±5–8 mm estimate)
- [ ] Picks and places a pen 10 times running without a failed grip
- [ ] Stability check passes with ballast in place
- [ ] 10-minute thermal soak completes with no servo uncomfortably hot
- [ ] `docs/requirements.md` fallback triggers reviewed — confirm none of
      them fired during testing, or record which configuration change they
      led to

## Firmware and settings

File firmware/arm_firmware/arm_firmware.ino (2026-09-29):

// arm_firmware.ino -- Desk Arm V1 firmware (ESP32 DevKit)
//
// Owns safety (joint limits, slew rate); the PC (software/) owns
// intelligence (kinematics, sequencing, and eventually the V2 agent).
// See docs/electronics.md for the architecture and full protocol table,
// docs/power_system.md for wiring rules, docs/assembly.md for the
// bring-up and calibration sequence this firmware is meant to support.
//
// Requires the "ESP32Servo" library (madhephaestus/ESP32Servo) instead of
// the stock Arduino Servo library -- the ESP32 core has no Servo.h of its
// own, and ESP32Servo drives the same writeMicroseconds()/attach() API on
// top of the LEDC PWM peripheral. Install it from Library Manager before
// building. Board package: "esp32" by Espressif Systems.
//
// Serial: 115200 baud, one ASCII command per line (newline-terminated),
// every command answered on its own line.
//
//   PING                    -> OK ARM v1
//   J <base> <sh> <el>      -> OK | ERR LIMIT <joint>     (degrees; wrist follows automatically)
//   G <0-100>               -> OK                          (0 = closed, 100 = open)
//   US <ch> <us>             -> OK | ERR RANGE               (ch = B/S/E/W/G, calibration only)
//   HOME                     -> OK
//   STOP                     -> OK
//   REL                      -> OK                          (detach all servos)
//   STAT                     -> <base> <sh> <el> <wrist> <grip%>  <usB> <usS> <usE> <usW> <usG>

#include <ESP32Servo.h>
#include "limits.h"
#include "slew.h"

// ---- Pin assignment ---------------------------------------------------
// Five GPIOs, all general-purpose and LEDC-PWM-capable. Deliberately not
// using: 0/2/5/12/15 (boot-strapping pins -- a servo yanking one of these
// low/high at power-on can change boot mode), 34-39 (input-only, can't
// drive a servo), or 1/3 (UART0 -- reserved for the USB serial link to the
// PC). See docs/electronics.md for the pin-selection rationale and the
// wiring diagram (docs/wiring_diagram.svg). Keep signal wires away from
// the barrel-jack leads (docs/electronics.md wiring notes).
const uint8_t PIN_BASE     = 13;
const uint8_t PIN_SHOULDER = 14;
const uint8_t PIN_ELBOW    = 27;
const uint8_t PIN_WRIST    = 26;
const uint8_t PIN_GRIPPER  = 25;

Servo servoBase, servoShoulder, servoElbow, servoWrist, servoGripper;

// ---- HOME pose ----------------------------------------------------------
// Starting defaults for the safe folded pose -- tune these during the
// calibration procedure in docs/assembly.md once the physical arm exists;
// they are not load-bearing for anything else in the firmware.
const float HOME_BASE_DEG     = 0.0f;
const float HOME_SHOULDER_DEG = 60.0f;
const float HOME_ELBOW_DEG    = -90.0f;
const int   HOME_GRIPPER_PCT  = 50;

// ---- Live state -----------------------------------------------------------
float curBase = HOME_BASE_DEG,     targetBase     = HOME_BASE_DEG;
float curShoulder = HOME_SHOULDER_DEG, targetShoulder = HOME_SHOULDER_DEG;
float curElbow = HOME_ELBOW_DEG,   targetElbow    = HOME_ELBOW_DEG;
float curWrist = 0.0f,             targetWrist    = 0.0f;
int   curGripperPct = HOME_GRIPPER_PCT;
bool  released = false;

unsigned long lastTickMs = 0;
const unsigned long TICK_MS = (unsigned long)(1000.0f / UPDATE_HZ);

// ---- Angle <-> microsecond mapping (linear per joint) ----------------------
long angleToUs(float angleDeg, float aMin, float aMax, int usMin, int usMax) {
  float t = (angleDeg - aMin) / (aMax - aMin);
  if (t < 0) t = 0;
  if (t > 1) t = 1;
  return usMin + (long)(t * (usMax - usMin));
}

float usToAngle(long us, float aMin, float aMax, int usMin, int usMax) {
  float t = (float)(us - usMin) / (float)(usMax - usMin);
  return aMin + t * (aMax - aMin);
}

// ---- Wrist slaving --------------------------------------------------------
// Keeps the gripper level in every pose: theta3 = -(theta1 + theta2).
// See docs/kinematics.md. Clamped to the wrist's own mechanical limits --
// if the slaved angle would exceed them, the pose itself is unreachable
// with a level gripper and the PC-side kinematics layer should have
// rejected it before ever sending J; the clamp here is a last-resort
// safety net, not the primary check.
float computeWristTarget(float shoulderDeg, float elbowDeg) {
  float w = -(shoulderDeg + elbowDeg);
  if (w < WRIST_ANGLE_MIN) w = WRIST_ANGLE_MIN;
  if (w > WRIST_ANGLE_MAX) w = WRIST_ANGLE_MAX;
  return w;
}

// ---- Setup ------------------------------------------------------------
void setup() {
  Serial.begin(115200);
  // ESP32Servo multiplexes servos across a handful of LEDC timers rather
  // than a per-pin hardware timer the way AVR's Servo library does; grab
  // all four up front so attach() below never fails to find one.
  ESP32PWM::allocateTimer(0);
  ESP32PWM::allocateTimer(1);
  ESP32PWM::allocateTimer(2);
  ESP32PWM::allocateTimer(3);
  attachAll();
  targetWrist = computeWristTarget(targetShoulder, targetElbow);
  curWrist = targetWrist;
  writeAll();
  lastTickMs = millis();
}

void attachAll() {
  // Pass each channel's real (min_us, max_us) explicitly -- ESP32Servo
  // defaults to clamping writeMicroseconds() to 544-2400us, which is
  // close but not identical to limits.h's per-joint ranges (e.g. shoulder
  // goes to 700-2400). Without this, out-of-band values silently clip
  // instead of reaching the servo, which is the opposite of what
  // limits.h's own range checks in handleLine() already guarantee.
  servoBase.setPeriodHertz(50);
  servoShoulder.setPeriodHertz(50);
  servoElbow.setPeriodHertz(50);
  servoWrist.setPeriodHertz(50);
  servoGripper.setPeriodHertz(50);
  servoBase.attach(PIN_BASE, BASE_US_MIN, BASE_US_MAX);
  servoShoulder.attach(PIN_SHOULDER, SHOULDER_US_MIN, SHOULDER_US_MAX);
  servoElbow.attach(PIN_ELBOW, ELBOW_US_MIN, ELBOW_US_MAX);
  servoWrist.attach(PIN_WRIST, WRIST_US_MIN, WRIST_US_MAX);
  servoGripper.attach(PIN_GRIPPER, GRIPPER_US_CLOSED, GRIPPER_US_OPEN);
  released = false;
}

void detachAll() {
  servoBase.detach();
  servoShoulder.detach();
  servoElbow.detach();
  servoWrist.detach();
  servoGripper.detach();
  released = true;
}

void writeAll() {
  if (released) return;
  servoBase.writeMicroseconds(angleToUs(curBase, BASE_ANGLE_MIN, BASE_ANGLE_MAX, BASE_US_MIN, BASE_US_MAX));
  servoShoulder.writeMicroseconds(angleToUs(curShoulder, SHOULDER_ANGLE_MIN, SHOULDER_ANGLE_MAX, SHOULDER_US_MIN, SHOULDER_US_MAX));
  servoElbow.writeMicroseconds(angleToUs(curElbow, ELBOW_ANGLE_MIN, ELBOW_ANGLE_MAX, ELBOW_US_MIN, ELBOW_US_MAX));
  servoWrist.writeMicroseconds(angleToUs(curWrist, WRIST_ANGLE_MIN, WRIST_ANGLE_MAX, WRIST_US_MIN, WRIST_US_MAX));
  long gUs = GRIPPER_US_CLOSED + (long)((curGripperPct / 100.0f) * (GRIPPER_US_OPEN - GRIPPER_US_CLOSED));
  servoGripper.writeMicroseconds(gUs);
}

// ---- Main loop --------------------------------------------------------
void loop() {
  pollSerial();

  unsigned long now = millis();
  if (now - lastTickMs >= TICK_MS) {
    lastTickMs = now;
    curBase     = slewStep(curBase, targetBase);
    curShoulder = slewStep(curShoulder, targetShoulder);
    curElbow    = slewStep(curElbow, targetElbow);
    curWrist    = slewStep(curWrist, targetWrist);
    writeAll();
  }
}

// ---- Serial command handling --------------------------------------------
void pollSerial() {
  static char buf[64];
  static uint8_t len = 0;

  while (Serial.available()) {
    char c = Serial.read();
    if (c == '\n' || c == '\r') {
      if (len > 0) {
        buf[len] = '\0';
        handleLine(buf);
        len = 0;
      }
    } else if (len < sizeof(buf) - 1) {
      buf[len++] = c;
    }
  }
}

void handleLine(char *line) {
  char *cmd = strtok(line, " ");
  if (cmd == nullptr) return;

  if (strcmp(cmd, "PING") == 0) {
    Serial.println("OK ARM v1");

  } else if (strcmp(cmd, "J") == 0) {
    char *aBase = strtok(nullptr, " ");
    char *aSh   = strtok(nullptr, " ");
    char *aEl   = strtok(nullptr, " ");
    if (!aBase || !aSh || !aEl) { Serial.println("ERR ARGS"); return; }
    float b = atof(aBase), s = atof(aSh), e = atof(aEl);

    if (b < BASE_ANGLE_MIN || b > BASE_ANGLE_MAX)         { Serial.println("ERR LIMIT base"); return; }
    if (s < SHOULDER_ANGLE_MIN || s > SHOULDER_ANGLE_MAX) { Serial.println("ERR LIMIT shoulder"); return; }
    if (e < ELBOW_ANGLE_MIN || e > ELBOW_ANGLE_MAX)       { Serial.println("ERR LIMIT elbow"); return; }

    float w = computeWristTarget(s, e);
    if (released) attachAll();
    targetBase = b; targetShoulder = s; targetElbow = e; targetWrist = w;
    Serial.println("OK");

  } else if (strcmp(cmd, "G") == 0) {
    char *aPct = strtok(nullptr, " ");
    if (!aPct) { Serial.println("ERR ARGS"); return; }
    int pct = atoi(aPct);
    if (pct < 0 || pct > 100) { Serial.println("ERR RANGE"); return; }
    if (released) attachAll();
    curGripperPct = pct;
    writeAll();
    Serial.println("OK");

  } else if (strcmp(cmd, "US") == 0) {
    char *aCh = strtok(nullptr, " ");
    char *aUs = strtok(nullptr, " ");
    if (!aCh || !aUs) { Serial.println("ERR ARGS"); return; }
    char ch = aCh[0];
    long us = atol(aUs);
    if (released) attachAll();

    switch (ch) {
      case 'B':
        if (us < BASE_US_MIN || us > BASE_US_MAX) { Serial.println("ERR RANGE"); return; }
        servoBase.writeMicroseconds(us);
        curBase = targetBase = usToAngle(us, BASE_ANGLE_MIN, BASE_ANGLE_MAX, BASE_US_MIN, BASE_US_MAX);
        break;
      case 'S':
        if (us < SHOULDER_US_MIN || us > SHOULDER_US_MAX) { Serial.println("ERR RANGE"); return; }
        servoShoulder.writeMicroseconds(us);
        curShoulder = targetShoulder = usToAngle(us, SHOULDER_ANGLE_MIN, SHOULDER_ANGLE_MAX, SHOULDER_US_MIN, SHOULDER_US_MAX);
        break;
      case 'E':
        if (us < ELBOW_US_MIN || us > ELBOW_US_MAX) { Serial.println("ERR RANGE"); return; }
        servoElbow.writeMicroseconds(us);
        curElbow = targetElbow = usToAngle(us, ELBOW_ANGLE_MIN, ELBOW_ANGLE_MAX, ELBOW_US_MIN, ELBOW_US_MAX);
        break;
      case 'W':
        if (us < WRIST_US_MIN || us > WRIST_US_MAX) { Serial.println("ERR RANGE"); return; }
        servoWrist.writeMicroseconds(us);
        curWrist = targetWrist = usToAngle(us, WRIST_ANGLE_MIN, WRIST_ANGLE_MAX, WRIST_US_MIN, WRIST_US_MAX);
        break;
      case 'G':
        if (us < GRIPPER_US_CLOSED || us > GRIPPER_US_OPEN) { Serial.println("ERR RANGE"); return; }
        servoGripper.writeMicroseconds(us);
        curGripperPct = (int)(100.0f * (us - GRIPPER_US_CLOSED) / (float)(GRIPPER_US_OPEN - GRIPPER_US_CLOSED));
        break;
      default:
        Serial.println("ERR ARGS");
        return;
    }
    Serial.println("OK");

  } else if (strcmp(cmd, "HOME") == 0) {
    if (released) attachAll();
    targetBase = HOME_BASE_DEG;
    targetShoulder = HOME_SHOULDER_DEG;
    targetElbow = HOME_ELBOW_DEG;
    targetWrist = computeWristTarget(HOME_SHOULDER_DEG, HOME_ELBOW_DEG);
    curGripperPct = HOME_GRIPPER_PCT;
    Serial.println("OK");

  } else if (strcmp(cmd, "STOP") == 0) {
    targetBase = curBase;
    targetShoulder = curShoulder;
    targetElbow = curElbow;
    targetWrist = curWrist;
    Serial.println("OK");

  } else if (strcmp(cmd, "REL") == 0) {
    detachAll();
    Serial.println("OK");

  } else if (strcmp(cmd, "STAT") == 0) {
    long usB = angleToUs(curBase, BASE_ANGLE_MIN, BASE_ANGLE_MAX, BASE_US_MIN, BASE_US_MAX);
    long usS = angleToUs(curShoulder, SHOULDER_ANGLE_MIN, SHOULDER_ANGLE_MAX, SHOULDER_US_MIN, SHOULDER_US_MAX);
    long usE = angleToUs(curElbow, ELBOW_ANGLE_MIN, ELBOW_ANGLE_MAX, ELBOW_US_MIN, ELBOW_US_MAX);
    long usW = angleToUs(curWrist, WRIST_ANGLE_MIN, WRIST_ANGLE_MAX, WRIST_US_MIN, WRIST_US_MAX);
    long usG = GRIPPER_US_CLOSED + (long)((curGripperPct / 100.0f) * (GRIPPER_US_OPEN - GRIPPER_US_CLOSED));

    Serial.print(curBase, 1);     Serial.print(' ');
    Serial.print(curShoulder, 1); Serial.print(' ');
    Serial.print(curElbow, 1);    Serial.print(' ');
    Serial.print(curWrist, 1);    Serial.print(' ');
    Serial.print(curGripperPct);  Serial.print("  ");
    Serial.print(usB); Serial.print(' ');
    Serial.print(usS); Serial.print(' ');
    Serial.print(usE); Serial.print(' ');
    Serial.print(usW); Serial.print(' ');
    Serial.println(usG);

  } else {
    Serial.println("ERR UNKNOWN");
  }
}

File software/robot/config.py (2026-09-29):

"""Single place to tune the robot: link lengths, joint limits, workspace
bounds, and per-servo calibration. Everything else in software/ imports
from here rather than hard-coding numbers, so Configurations A/B/C/D
(docs/requirements.md) differ by editing this file, not by editing code.

Values below are Configuration B (docs/requirements.md), and mirror the
constants in firmware/arm_firmware/limits.h -- if you change a range here,
change it there too, and vice versa. The firmware's copy is authoritative
for what the hardware will actually accept; this copy lets software reject
bad targets before anything reaches the serial port (docs/kinematics.md
validation order).
"""

from __future__ import annotations
from dataclasses import dataclass

# ---------------------------------------------------------------------------
# Geometry, metres (docs/requirements.md / docs/kinematics.md)
# ---------------------------------------------------------------------------
L1 = 0.120   # upper arm
L2 = 0.120   # forearm
L3 = 0.075   # wrist -> TCP
H0 = 0.075   # shoulder height above the table


# ---------------------------------------------------------------------------
# Joint limits, degrees (must match firmware/arm_firmware/limits.h)
# ---------------------------------------------------------------------------
BASE_MIN_DEG, BASE_MAX_DEG = -90.0, 90.0
SHOULDER_MIN_DEG, SHOULDER_MAX_DEG = 0.0, 110.0
ELBOW_MIN_DEG, ELBOW_MAX_DEG = -130.0, 0.0
WRIST_MIN_DEG, WRIST_MAX_DEG = -120.0, 30.0

# Safe folded pose -- must match HOME_*_DEG in
# firmware/arm_firmware/arm_firmware.ino. robot.arm.Arm assumes the
# physical (or simulated) arm starts here until the first STAT reply is
# read back, since the ESP32 doesn't report its pose on connect.
HOME_BASE_DEG = 0.0
HOME_SHOULDER_DEG = 60.0
HOME_ELBOW_DEG = -90.0


# ---------------------------------------------------------------------------
# Workspace bounds, metres (docs/kinematics.md / docs/requirements.md)
# ---------------------------------------------------------------------------
WORKSPACE_R_MIN = 0.130   # forearm-to-turret collision boundary
WORKSPACE_R_MAX = 0.290   # practical outer limit (290mm; kinematic max is 315mm --
                           # the last 25mm is a near-singularity, see docs/kinematics.md)
TABLE_CLEARANCE_Z = 0.010  # minimum jaw height above the table


# ---------------------------------------------------------------------------
# Motion
# ---------------------------------------------------------------------------
MAX_SLEW_DEG_S = 60.0          # must match firmware/arm_firmware/slew.h
CARTESIAN_PATH_STEPS = 20      # waypoints checked per move_to() (docs/kinematics.md)


# ---------------------------------------------------------------------------
# Per-servo calibration -- fill in during docs/assembly.md's calibration
# step. (min_us, max_us) is that channel's usable pulse range; angle_offset_deg
# is added to the *commanded* angle before it's sent, to correct for the
# servo not landing exactly where the geometry says 0 degrees should be.
# Defaults below are uncalibrated placeholders -- the wide-open
# 500-2500us range and zero offset -- and MUST be replaced with real
# measurements before trusting move_to() accuracy.
# ---------------------------------------------------------------------------

@dataclass
class ServoCal:
    channel: str          # matches firmware US <ch> codes: B/S/E/W/G
    min_us: int
    max_us: int
    angle_offset_deg: float = 0.0


SERVO_CAL = {
    "base":     ServoCal("B", 900, 2100),
    "shoulder": ServoCal("S", 700, 2400),
    "elbow":    ServoCal("E", 700, 2400),
    "wrist":    ServoCal("W", 900, 2100),
    "gripper":  ServoCal("G", 1000, 1900),
}


# ---------------------------------------------------------------------------
# Transport defaults
# ---------------------------------------------------------------------------
DEFAULT_BAUD = 115200
DEFAULT_TIMEOUT_S = 2.0

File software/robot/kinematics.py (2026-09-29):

"""Forward and inverse kinematics for the 3-DOF arm + slaved wrist.

Derivation and the reasoning behind every design choice here (why the
elbow-up root, why the wrist is slaved rather than commanded, why
validation runs in this exact order) is in docs/kinematics.md -- this file
is the implementation of that document, not an independent source of truth.

No hardware needed to use or test this module:

    python -m robot.kinematics

runs a self-test that round-trips fk(ik(target)) for several points across
the workspace and checks that the validation functions reject the cases
docs/kinematics.md says they should.
"""

from __future__ import annotations
from dataclasses import dataclass
from math import atan2, acos, sin, cos, sqrt, degrees, radians, isclose

from . import config


class UnreachableError(ValueError):
    """Raised by ik() when a target has no valid joint solution."""


@dataclass
class Pose:
    x: float
    y: float
    z: float


@dataclass
class Joints:
    base_deg: float
    shoulder_deg: float
    elbow_deg: float
    wrist_deg: float


# ---------------------------------------------------------------------------
# Forward kinematics
# ---------------------------------------------------------------------------

def fk(base_deg: float, shoulder_deg: float, elbow_deg: float) -> Pose:
    """Joint angles -> end-effector position. Wrist is always the slaved
    angle -(shoulder+elbow), so it contributes no separate trig term to r
    (docs/kinematics.md) -- L3 just adds directly to the radius."""
    t0, t1, t2 = radians(base_deg), radians(shoulder_deg), radians(elbow_deg)
    r = config.L1 * cos(t1) + config.L2 * cos(t1 + t2) + config.L3
    z = config.H0 + config.L1 * sin(t1) + config.L2 * sin(t1 + t2)
    x = r * cos(t0)
    y = r * sin(t0)
    return Pose(x, y, z)


def wrist_deg_for(shoulder_deg: float, elbow_deg: float) -> float:
    """The slaved wrist angle that keeps the gripper level. Firmware
    computes and clamps this independently as a safety net
    (firmware/arm_firmware/arm_firmware.ino); this is the same formula so
    software-side reachability checks agree with what the hardware will
    actually do."""
    w = -(shoulder_deg + elbow_deg)
    return max(config.WRIST_MIN_DEG, min(config.WRIST_MAX_DEG, w))


# ---------------------------------------------------------------------------
# Inverse kinematics
# ---------------------------------------------------------------------------

def ik(x: float, y: float, z: float) -> Joints:
    """Desired (x, y, z) -> joint angles. Raises UnreachableError with a
    specific reason rather than returning a best-effort answer -- callers
    (robot.arm.Arm) are expected to validate with reachable() first and
    treat this as a hard boundary, not something to catch-and-clamp."""
    base_deg = degrees(atan2(y, x))

    r_prime = sqrt(x * x + y * y) - config.L3
    z_prime = z - config.H0

    L1, L2 = config.L1, config.L2
    denom = 2 * L1 * L2
    if denom == 0:
        raise UnreachableError("degenerate link lengths")

    d = (r_prime**2 + z_prime**2 - L1**2 - L2**2) / denom
    if d < -1.0 or d > 1.0:
        raise UnreachableError(
            f"target ({x*1000:.0f}, {y*1000:.0f}, {z*1000:.0f}) mm is outside "
            f"the two-link reach envelope (|D|={d:.3f} > 1)"
        )

    elbow_rad = -acos(d)  # negative root = elbow-up (docs/kinematics.md)
    shoulder_rad = atan2(z_prime, r_prime) - atan2(
        L2 * sin(elbow_rad), L1 + L2 * cos(elbow_rad)
    )

    shoulder_deg = degrees(shoulder_rad)
    elbow_deg = degrees(elbow_rad)
    wrist_deg = wrist_deg_for(shoulder_deg, elbow_deg)

    return Joints(base_deg, shoulder_deg, elbow_deg, wrist_deg)


# ---------------------------------------------------------------------------
# Validation -- run in this order before anything moves (docs/kinematics.md)
# ---------------------------------------------------------------------------

def reachable(x: float, y: float, z: float) -> tuple[bool, str]:
    """1) Reachability, 2) joint limits, 3) table clearance. Returns
    (ok, reason) -- reason is "" when ok."""
    r = sqrt(x * x + y * y)
    if not (config.WORKSPACE_R_MIN <= r <= config.WORKSPACE_R_MAX):
        return False, (
            f"radius {r*1000:.0f} mm outside workspace "
            f"[{config.WORKSPACE_R_MIN*1000:.0f}, {config.WORKSPACE_R_MAX*1000:.0f}] mm"
        )

    if z < config.TABLE_CLEARANCE_Z:
        return False, f"z={z*1000:.1f} mm below table clearance floor ({config.TABLE_CLEARANCE_Z*1000:.0f} mm)"

    try:
        j = ik(x, y, z)
    except UnreachableError as e:
        return False, str(e)

    if not (config.BASE_MIN_DEG <= j.base_deg <= config.BASE_MAX_DEG):
        return False, f"base {j.base_deg:.1f} deg outside [{config.BASE_MIN_DEG}, {config.BASE_MAX_DEG}]"
    if not (config.SHOULDER_MIN_DEG <= j.shoulder_deg <= config.SHOULDER_MAX_DEG):
        return False, f"shoulder {j.shoulder_deg:.1f} deg outside [{config.SHOULDER_MIN_DEG}, {config.SHOULDER_MAX_DEG}]"
    if not (config.ELBOW_MIN_DEG <= j.elbow_deg <= config.ELBOW_MAX_DEG):
        return False, f"elbow {j.elbow_deg:.1f} deg outside [{config.ELBOW_MIN_DEG}, {config.ELBOW_MAX_DEG}]"

    return True, ""


def path_safe(p0: Pose, p1: Pose, steps: int = config.CARTESIAN_PATH_STEPS) -> tuple[bool, str]:
    """4) Path check: a straight line between two individually-legal poses
    can still pass through an illegal one (docs/kinematics.md) -- interpolate
    and validate every waypoint, not just the endpoints."""
    for i in range(steps + 1):
        t = i / steps
        x = p0.x + t * (p1.x - p0.x)
        y = p0.y + t * (p1.y - p0.y)
        z = p0.z + t * (p1.z - p0.z)
        ok, reason = reachable(x, y, z)
        if not ok:
            return False, f"waypoint {i}/{steps} at t={t:.2f}: {reason}"
    return True, ""


# ---------------------------------------------------------------------------
# Self-test -- no hardware required
# ---------------------------------------------------------------------------
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

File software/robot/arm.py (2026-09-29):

"""robot.arm.Arm -- the six calls everything else is meant to use.

This is the V1 <-> V2 contract (docs/v2_ai_roadmap.md): the CLI
(software/cli.py), the demo sequences (software/sequences.py), and
eventually a V2 agent all drive the robot through this class and nothing
lower-level. If V2 ever needs to reach past this API to work, that's a
sign the API was drawn in the wrong place -- not a reason to add a
backdoor.

    from robot.arm import Arm

    with Arm(port="COM5") as arm:
        arm.home()
        arm.pickup(0.200, 0.050, 0.015)
        arm.place(0.150, -0.100, 0.015)

Pass port=None to run against a SimulatedTransport (see robot.transport) --
useful for exercising sequences before any hardware is wired up.
"""

from __future__ import annotations
import time
from typing import Optional

from . import config
from .kinematics import Joints, Pose, fk, ik, reachable, path_safe, UnreachableError
from .trajectory import interpolate_joints
from .transport import SerialTransport, SimulatedTransport, TransportError


class Arm:
    def __init__(self, port: Optional[str] = None, verbose: bool = False):
        self._verbose = verbose
        self._transport = SerialTransport(port) if port else SimulatedTransport()
        # Assumed starting pose -- the ESP32 doesn't report position on
        # connect, so this matches its HOME_*_DEG defaults (config.py /
        # firmware/arm_firmware/arm_firmware.ino) until the first move.
        self._current = Joints(config.HOME_BASE_DEG, config.HOME_SHOULDER_DEG,
                                config.HOME_ELBOW_DEG, 0.0)

    # -- lifecycle ------------------------------------------------------
    def connect(self) -> None:
        self._transport.connect()

    def close(self) -> None:
        self._transport.close()

    def __enter__(self) -> "Arm":
        self.connect()
        return self

    def __exit__(self, *exc) -> None:
        self.close()

    # -- the six public calls --------------------------------------------
    def home(self) -> None:
        """Slew to the safe folded pose (firmware-defined -- see
        firmware/arm_firmware/arm_firmware.ino HOME_*_DEG)."""
        self._send("HOME")
        self._current = Joints(config.HOME_BASE_DEG, config.HOME_SHOULDER_DEG,
                                config.HOME_ELBOW_DEG, 0.0)

    def move_joints(self, base_deg: float, shoulder_deg: float, elbow_deg: float) -> None:
        """Absolute joint command. Firmware computes and clamps the slaved
        wrist angle itself; software validates against the same limits
        first so a bad call fails locally instead of round-tripping to
        the ESP32 to find out."""
        self._check_joint_limits(base_deg, shoulder_deg, elbow_deg)
        self._send(f"J {base_deg:.1f} {shoulder_deg:.1f} {elbow_deg:.1f}")
        self._current = Joints(base_deg, shoulder_deg, elbow_deg,
                                -(shoulder_deg + elbow_deg))

    def move_to(self, x: float, y: float, z: float, steps: int = config.CARTESIAN_PATH_STEPS) -> None:
        """Cartesian move, fully validated before a single servo moves
        (docs/kinematics.md's four-stage check) and interpolated in joint
        space with easing (robot.trajectory) rather than jumping straight
        to the target."""
        ok, reason = reachable(x, y, z)
        if not ok:
            raise UnreachableError(reason)

        target = ik(x, y, z)
        current_pose = fk(self._current.base_deg, self._current.shoulder_deg, self._current.elbow_deg)
        path_ok, path_reason = path_safe(current_pose, Pose(x, y, z), steps=steps)
        if not path_ok:
            raise UnreachableError(f"path rejected: {path_reason}")

        for waypoint in interpolate_joints(self._current, target, steps):
            self.move_joints(waypoint.base_deg, waypoint.shoulder_deg, waypoint.elbow_deg)

    def grip(self, percent: int) -> None:
        """0 = closed, 100 = open."""
        if not (0 <= percent <= 100):
            raise ValueError(f"grip percent {percent} outside [0, 100]")
        self._send(f"G {percent}")

    def pickup(self, x: float, y: float, z: float,
               approach_height: float = 0.040, settle_s: float = 0.3) -> None:
        """Approach from above, descend, close, lift -- see
        docs/v2_ai_roadmap.md for why this shape (rather than a direct
        move-and-close) is what a future vision-driven pick also wants:
        the approach point only needs an (x, y) from a camera plus a
        fixed height, sidestepping most depth-estimation error."""
        self.grip(100)
        self.move_to(x, y, z + approach_height)
        self.move_to(x, y, z)
        time.sleep(settle_s)
        self.grip(0)
        time.sleep(settle_s)
        self.move_to(x, y, z + approach_height)

    def place(self, x: float, y: float, z: float,
              approach_height: float = 0.040, settle_s: float = 0.3) -> None:
        """Mirror of pickup(): approach from above, descend, release, retreat."""
        self.move_to(x, y, z + approach_height)
        self.move_to(x, y, z)
        time.sleep(settle_s)
        self.grip(100)
        time.sleep(settle_s)
        self.move_to(x, y, z + approach_height)

    # -- lower-level, used by the CLI for bring-up/debugging ------------------
    def stop(self) -> None:
        self._send("STOP")

    def release(self) -> None:
        """Detach all servos -- lets the arm be moved by hand
        (docs/assembly.md calibration procedure)."""
        self._send("REL")

    def status(self) -> str:
        return self._send("STAT")

    def raw_pulse(self, channel: str, microseconds: int) -> None:
        """Calibration-only escape hatch -- still bounded by
        firmware/arm_firmware/limits.h on the hardware side regardless of
        what's sent here."""
        self._send(f"US {channel} {microseconds}")

    # -- internals --------------------------------------------------------
    def _check_joint_limits(self, base_deg: float, shoulder_deg: float, elbow_deg: float) -> None:
        if not (config.BASE_MIN_DEG <= base_deg <= config.BASE_MAX_DEG):
            raise ValueError(f"base {base_deg} outside [{config.BASE_MIN_DEG}, {config.BASE_MAX_DEG}]")
        if not (config.SHOULDER_MIN_DEG <= shoulder_deg <= config.SHOULDER_MAX_DEG):
            raise ValueError(f"shoulder {shoulder_deg} outside [{config.SHOULDER_MIN_DEG}, {config.SHOULDER_MAX_DEG}]")
        if not (config.ELBOW_MIN_DEG <= elbow_deg <= config.ELBOW_MAX_DEG):
            raise ValueError(f"elbow {elbow_deg} outside [{config.ELBOW_MIN_DEG}, {config.ELBOW_MAX_DEG}]")

    def _send(self, line: str) -> str:
        if self._verbose:
            print(f">> {line}")
        try:
            reply = self._transport.send(line)
        except TransportError:
            raise
        if self._verbose:
            print(f"<< {reply}")
        return reply

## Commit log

2026-09-29 Initial commit: Desk Arm V1 — requirements, mechanical/electrical design, ESP32 firmware, Python control layer, engineering calcs, wiring diagram
    Configuration B (315mm reach, 55g payload, MG996R/MG90S/SG90 servos, ESP32
    controller). Phase 0 requirements complete, CAD not yet started.
2026-09-29 Update design_review.html for the ESP32 controller swap
    Controller, cost, pin/library notes, and the 3.3V servo-jitter risk now
    match docs/electronics.md; noted in artifacts/README.md as an in-place
    update rather than a footnoted discrepancy.
2026-09-29 Document 4xAA batteries as a rejected power source
    Nominal voltage is fine but alkaline internal resistance causes too much
    sag under the servo rail's real current draw. Added to power_system.md's
    sourcing table and mirrored into planning_guide.tex/pdf.
2026-09-29 Document milled steel ballast; record gearmotor/encoder payload upgrade as a separate V2 track
    Ballast: solid milled mild-steel block (~60x60x15mm, ~424g) replaces
    generic loose fill -- fixed known mass at a fixed position matches the
    stability calc's assumption and won't shift CoM during base rotation.
    Sized ahead of CAD (Phase 2 hasn't started), added to mechanical_design.md,
    assembly.md, cad/README.md and bill_of_materials.md, mirrored in the
    planning guide.
    V2 roadmap: recorded a gearmotor + planetary gearbox + encoder actuator
    path as its own track, explicitly decoupled from the AI/vision stages
    (2.1-2.4) that V2 originally scoped -- different axis (payload/actuation
    vs. perception), n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
2026-09-30 Add CAD equations file
2026-09-30 New global variable (m3 gripper pin)
2026-10-01 Record measured c_fit (0.2 mm, PLA) and set c_fit_pivot to 0.25 mm
    Tolerance coupon on Prusa Core One + Prusament PLA: +0.20 mm gave the best
    snug fit on both M4 and M3 holes, confirming the c_fit default. PETG still
    untested. c_fit_pivot set to c_fit + 0.05 mm by choice; documented the new
    d_pin_gripper / c_fit_pivot variables in cad/README.md.
2026-10-05 Add w_link/w_gap variables and link side plate spec
    New global variables for link plate depth (20 mm, matches the deflection
    calc) and the provisional twin-plate gap (set by the elbow servo mount).
    cad/README.md gains a link side plate spec and updated part notes.
2026-10-05 Add upper arm plate, arm overview + joint diagrams, ignore SolidWorks lock files
    [upper_arm_plate.SLDPRT]
2026-10-14 Update upper arm plate (tapered, linked to variables), add hole formulas, add MG996R model
2026-10-14 Add spacer holes to upper arm plate
2026-10-14 Add upper arm spacer, update README spacer entry
2026-10-14 Raise t_rim to 9.5 mm, add MockShoulder assembly, update plate and spacer
2026-10-23 Add shoulder horn adapter, countersunk holes on upper arm plate, update MockShoulder
2026-10-23 Add shoulder bracket layout drawing and variables
2026-10-23 Add shoulder bracket part, update drawing and notes to final foot
2026-10-23 Fix bracket ear holes and rib notches, rebuild MockShoulder around bracket, update handoff
2026-10-23 Extend bracket foot for insert edge material, update handoff and notes
2026-10-23 Set M3 insert hole to 4.0 mm for the HZYUEGOU inserts, update notes
2026-10-24 Link all bracket and adapter dimensions to equations, add 10 bracket variables, fix duplicate imports
2026-10-24 Add solid forearm and elbow servo mount variables, elbow concept drawing, update handoff
